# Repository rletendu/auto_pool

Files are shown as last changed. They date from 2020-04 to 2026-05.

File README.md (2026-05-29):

# AutoPool

ESP32 swimming-pool controller with pH / ORP / filter automation, Nextion touch UI, web dashboard, MQTT, and native Home Assistant autodiscovery.

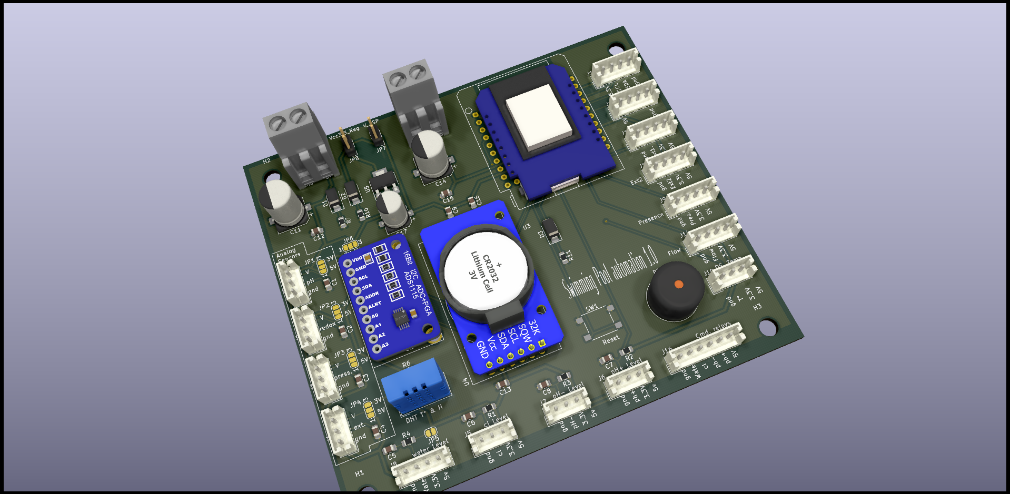
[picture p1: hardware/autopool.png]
AutoPool


AutoPool runs unattended on the side of the pool: it schedules the filter pump, doses chlorine on ORP, holds pH inside a target band by injecting acid (and optionally base) through peristaltic pumps, watches tank levels, and exposes everything over a 5″ touch panel, a web UI, and MQTT.

---

## Table of contents

- [Features](#features)
- [Hardware](#hardware)
- [Architecture](#architecture)
- [Build, flash and first boot](#build-flash-and-first-boot)
- [Configuration](#configuration)
- [MQTT](#mqtt)
- [Home Assistant integration](#home-assistant-integration)
- [Web UI and Nextion display](#web-ui-and-nextion-display)
- [OTA, CLI and Telnet](#ota-cli-and-telnet)
- [ESPHome alternative](#esphome-alternative)
- [Repository layout](#repository-layout)
- [Credits and license](#credits-and-license)

---

## Features

**Regulation**
- Filter pump scheduling — 24-hour fixed bitmap or per-temperature program (selected by `filter_auto_mode`)
- Filter speed control (FULL / REG) on a variable-speed pump
- Periodic short-cycle filter run for stagnation prevention
- pH minus (and optional pH plus) dosing on a fixed regulation cycle, proportional to deviation from target
- ORP / chlorine dosing on a fixed regulation cycle with daily mL caps
- Daily injection counters with automatic midnight reset (preserved across soft resets via RTC slow memory)

**Sensing**
- DS18B20 — water temperature (OneWire)
- DHT22 — air temperature and humidity inside the enclosure
- ADS1115 — pH probe, ORP probe, and pump-loop pressure transducer (3 channels)
- DS3231 — battery-backed RTC
- Four float switches — water level + Cl / pH- / pH+ tank levels

**Interfaces**
- Nextion 5″ resistive touch panel (`hmi/auto_pool_ui.HMI`)
- Responsive web dashboard served from SPIFFS (`http://<ip>/`)
- MQTT — measures, states, parameters, log, command, with **Home Assistant autodiscovery** (~40 entities) and LWT availability
- Serial CLI (`SimpleCLI`)
- OTA — firmware, SPIFFS filesystem, and Nextion display

---

## Hardware

The full schematic and PCB live in [`hardware/`](hardware/):

- [`hardware/autopool.pdf`](hardware/autopool.pdf) — schematic
- [`hardware/autopool.kicad_pcb`](hardware/autopool.kicad_pcb) — KiCad PCB
- [`hardware/autopool.png`](hardware/autopool.png), [`autopool_3.png`](hardware/autopool_3.png) — board renders
- [`3D/`](3D/) — printable enclosure parts (STL / STEP)

### Bill of materials (top level)

| Block | Part |
|---|---|
| MCU | ESP32 dev module |
| Display | Nextion 5″ (NX8048T050 or compatible) |
| Analog frontend | ADS1115 (I²C) for pH / ORP / pressure |
| RTC | DS3231 (I²C, battery-backed) |
| Air sensor | DHT22 |
| Water sensor | DS18B20 (OneWire) |
| Filter pump driver | Solid-state relay (active-high) |
| Dosing | 3× peristaltic pumps (Cl, pH-, pH+) on relays (active-low) |
| Levels | 4× float switches (water, Cl, pH-, pH+) |
| Misc | Piezo buzzer, two status LEDs |

### Pin map (excerpt, see [`src/board.h`](src/board.h) for the source of truth)

| Function | GPIO | Notes |
|---|---|---|
| Filter pump SSR | `PIN_EXT1` (14) | active **high** (`PUMP_FILTER_ACTIVE_VALUE = true`) |
| Filter speed (FULL/REG) | `PIN_EXT2` (15) | optional, gated by `HAS_FILTER_PWR_CTRL` |
| Cl pump relay | 25 | active **low** (`PUMP_ACTIVE_VALUE = false`) |
| pH- pump relay | 32 | active low |
| pH+ pump relay | 4 | active low, gated by `HAS_PH_PLUS_PUMP` |
| DS18B20 (water temp) | 13 | OneWire |
| DHT22 | 18 | |
| I²C (ADS1115, DS3231) | 21 / 22 | SDA / SCL |
| Nextion display | 16 / 17 | `Serial2` RX / TX, 115 200 baud |
| Float switches | 34, 35, 36, 39 | water / Cl / pH- / pH+ (input-only pins) |
| Buzzer | 5 | |

> **Polarity matters.** The filter pump SSR is wired through `PIN_EXT1` and is active-high; the dosing relays are active-low. Always go through the helpers in `board.h` (`pump_filtration_on/off`, `pump_ph_minus_on/off`, …) — never `digitalWrite` directly from feature code.

---

## Architecture

```
                    ┌────────────────────────┐
                    │       main.cpp         │
                    │  setup() / loop()      │
                    └──────────┬─────────────┘
                               │ SoftTimer ticks
        ┌──────────────┬───────┴───────┬──────────────┐
        ▼              ▼               ▼              ▼
  filter_control   ph_control     orp_control     measures
   (state machine) (state machine)(state machine) (sensor reads)
        │              │               │              │
        └────────┬─────┴────────┬──────┴──────┬───────┘
                 ▼              ▼             ▼
              board.h        state.h     parameters.h
            (HW helpers)   (live state)  (persisted setpoints)
                 │              │             │
                 ▼              ▼             ▼
        ┌────────────────────────────────────────────┐
        │   display  │  mqtt  │  server  │  cli  │ ota │
        └────────────────────────────────────────────┘
```

- **Cooperative scheduling** — every subsystem registers periodic work on a [`SoftTimer`](src/soft_timer.h) instance; no `delay()` in the main loop.
- **Three regulators** with explicit state machines defined in [`src/state.h`](src/state.h):
  - `filter_control_state_t` — IDLE → WARM_UP → ACTIVE → EXTENDED → PERIODIC
  - `ph_control_state_t` — IDLE / MINUS_INJECTION_{ON,OFF} / PLUS_INJECTION_{ON,OFF}
  - `orp_control_state_t` — IDLE / INJECTION_{ON,OFF}
- **Persistence** — two SPIFFS JSON files in [`data/`](data/):
  - `/config.json` ↔ `ParametersStruture` ([`src/parameters.h`](src/parameters.h))
  - `/state.json` ↔ last-known mode of each regulator (so a reboot does not reset operator intent)
- **Compile-time feature gates** in [`src/config.h`](src/config.h): `HAS_PH_CONTROL`, `HAS_ORP_CONTROL`, `HAS_FILTER_CONTROL`, `HAS_FILTER_PWR_CTRL`, `HAS_PH_PLUS_PUMP`, `HAS_MQTT`, `HAS_OTA`, `HAS_WEB_SERVER`, `HAS_CLI`, `HAS_TELNET_SERVER`, `HAS_QUIET_MEASURES`, `HAS_CUSTOM_MAC`.

---

## Build, flash and first boot

PlatformIO is the only toolchain. The single environment is `esp32dev`, defined in [`platformio.ini`](platformio.ini).

```bash
# Build
pio run

# Flash firmware over USB
pio run -t upload

# Flash firmware OTA
pio run -t upload --upload-port 192.168.x.x

# Flash the SPIFFS filesystem (web UI + config.json + state.json)
# Required after editing anything under data/
pio run -t uploadfs

# Serial monitor at 115 200 baud
pio device monitor

# Clean build
pio run -t clean
```

> **Firmware vs. filesystem are two independent flashes.** `pio run -t upload` writes the application binary (everything compiled from `src/`); `pio run -t uploadfs` writes the SPIFFS image built from `data/` (web UI, `config.json`, `state.json`). They're independent partitions on the ESP32 — flashing one never touches the other. Rules of thumb:
>
> - **Edited C/C++ in `src/` or `lib/`** → `pio run -t upload`. No `uploadfs` needed; settings and web assets are untouched.
> - **Edited anything under `data/`** (web UI, default `config.json`) → `pio run -t uploadfs`. No firmware reflash needed.
> - **Both** → run them in either order; e.g. `pio run -t upload && pio run -t uploadfs`.
> - **OTA**: both targets accept `--upload-port <ip>` to flash over Wi-Fi via `espota`, e.g. `pio run -t uploadfs --upload-port 192.168.x.x`.
> - **Heads up on `uploadfs`**: it overwrites `config.json` with the version in `data/`, wiping any settings the user changed via the web UI / portal / MQTT. Pull the live config back first (`curl http://<ip>/getparameters > data/config.json`) if you want to preserve it.

> **There are no unit tests** wired up. `test/autopool_tester.py` is a host-side helper, not a PlatformIO test runner.

### First boot

On first power-up the device opens a captive Wi-Fi portal named **`AUTOPOOL_CONFIG`**. Connect to it and configure:

- Wi-Fi SSID / password
- MQTT server / port / user / password
- MQTT base topic (default: `autopool`)

Settings persist to `/config.json` on SPIFFS. To re-trigger the portal later, send the `portal` CLI command on the serial console, or hit `/reboot` after wiping settings via `portal_reset`.

---

## Configuration

Three editing channels feed the same [`ParametersStruture`](src/parameters.h):

1. **Web UI** — `http://<ip>/settings.html` (form is bound by [`data/script_settings.js`](data/script_settings.js))
2. **MQTT** — publish a full JSON payload to `<base>/CMD/PARAMETERS`, or update one field at a time with `<base>/CMD/SET/<KEY>` *(see [MQTT](#mqtt))*
3. **WiFiManager portal** — for the network and broker fields only, on first boot or after `portal` / `portal_reset`

### Most-edited parameters

| Field | Meaning | Typical |
|---|---|---|
| `target_ph`, `delta_ph` | pH setpoint and dead-band | 7.4 ± 0.15 |
| `target_orp`, `delta_orp` | ORP setpoint (mV) and dead-band | 650 ± 70 |
| `flow_cl`, `flow_ph_minus`, `flow_ph_plus` | Peristaltic pump flow rate (mL/min) | 25 |
| `cl_max_day`, `phm_max_day` | Daily injection caps (mL) | 2000 |
| `pressure_warning` | Filter loop alarm threshold (bar) | 1.9 |
| `ph_offset`, `orp_offset` | Probe calibration offsets | 0 |
| `timer_prog` | 24-bit hourly bitmap for filter run | — |
| `filter_auto_mode` | `0` = bitmap, `1` = function of water temperature | 0 |
| `timer_prog_temperature[11]` | Per-temperature bitmaps (10 °C → 30 °C, step 2 °C) | — |
| `periodic_filter_time` | Seconds for short anti-stagnation cycle | 0 |
| `ha_discovery_enabled`, `ha_discovery_prefix` | HA autodiscovery toggle and topic prefix | `false`, `homeassistant` |

---

## MQTT

All topics are rooted at `<base>` (the value of `mqtt_base_topic`, default `autopool`).

### Published

| Topic | Retained | Payload |
|---|---|---|
| `<base>/AVAIL` | yes | `online` while the controller is up; `offline` published as LWT on disconnect |
| `<base>/MEAS` | no | JSON snapshot of [`MeasuresStructure`](src/measures.h) (temps, pH, ORP, pressure, levels, daily mL counters, boot count) |
| `<base>/STATE_FILTER` | no | JSON snapshot of the filter regulator state |
| `<base>/STATE_PH` | no | JSON snapshot of the pH± regulator state |
| `<base>/STATE_ORP` | no | JSON snapshot of the ORP regulator state |
| `<base>/PARAM` | no | Echo of the current `ParametersStruture` after any change |
| `<base>/LOG`, `<base>/DEBUG` | no | Free-form text |
| `<prefix>/+/autopool_<mac>/+/config` | yes | HA discovery configs (only when `ha_discovery_enabled` is set) |

### Subscribed (`<base>/CMD/<KEY>`)

**Mode commands** *(legacy string suffix, empty payload):*
`FILTER_MODE_AUTO` · `FILTER_MODE_ON` · `FILTER_MODE_OFF` · `FILTER_PWR_FULL` · `FILTER_PWR_REG` · `ORP_MODE_AUTO` · `ORP_MODE_ON` · `ORP_MODE_OFF`

**Per-field SET commands** *(payload = scalar value, suitable for HA selects/numbers):*

| Topic | Payload |
|---|---|
| `SET/FILTER_MODE` | `AUTO` \| `ON` \| `OFF` |
| `SET/FILTER_POWER` | `FULL` \| `REG` |
| `SET/ORP_MODE` | `AUTO` \| `ON` \| `OFF` |
| `SET/PH_MINUS_MODE` | `AUTO` \| `ON` \| `OFF` |
| `SET/PH_PLUS_MODE` | `AUTO` \| `ON` \| `OFF` |
| `SET/TARGET_PH`, `SET/DELTA_PH` | float |
| `SET/TARGET_ORP`, `SET/DELTA_ORP` | float (mV) |
| `SET/FLOW_CL`, `SET/FLOW_PH_MINUS`, `SET/FLOW_PH_PLUS` | float (mL/min) |
| `SET/CL_MAX_DAY`, `SET/PHM_MAX_DAY` | float (mL) |
| `SET/PRESSURE_WARNING` | float (bar) |
| `SET/PH_OFFSET`, `SET/ORP_OFFSET` | float (calibration) |
| `SET/PERIODIC_FILTER_TIME` | seconds |

Per-field SET commands persist to `/config.json` and echo on `<base>/PARAM`.

**JSON updates** *(payload = full JSON document):*
`PARAMETERS` · `MEASURES` · `FILTER_STATE` · `ORP_STATE` · `PH_STATE`

**Utility:** `RESET` · `RST_DAILY_ML_ORP` · `BEEP` · `GET_PARAMETERS` · `GET_STATES` · `LOG` · `FS`

---

## Home Assistant integration

Two paths, pick one.

### Autodiscovery (recommended)

1. Open the AutoPool web UI → **Settings** → tick **Enable autodiscovery**, leave the prefix as `homeassistant` unless your HA instance uses a custom one.
2. Click **Submit**. The controller publishes ~40 retained discovery configs under `<prefix>/+/autopool_<mac>/+/config`.
3. Home Assistant's MQTT integration picks them up automatically. AutoPool appears as a single device with:
   - Sensors — water / system temperature, humidity, pressure, pH, ORP, daily mL counters, boot count
   - Binary sensors — water level, three tank levels, four pump-running indicators
   - Selects — filter mode, filter power, ORP mode, pH± modes
   - Numbers — every setpoint listed in [Configuration](#configuration)
   - Buttons — controller reset, daily Cl counter reset
   - Diagnostic sensors — internal state of the three regulators
4. To remove the device: untick the checkbox; the controller publishes empty retained payloads to clear every discovery topic.

The companion dashboard at [`homeassistant/dashboards/autopool.yaml`](homeassistant/dashboards/autopool.yaml) is wired entirely to the autodiscovered entity_ids (`<domain>.autopool_<object>`, courtesy of the `obj_id` field in each discovery payload). It uses only stock Lovelace cards — no HACS install required. Drop it under `<HA_config>/dashboards/` and register it via the `lovelace.dashboards` block in [`homeassistant/configuration_snippet.yaml`](homeassistant/configuration_snippet.yaml).

### Multi-device deployment

Two AutoPool controllers can share a single MQTT broker and a single Home Assistant instance. Set `device_suffix` on each one — short, lowercase, `[a-z0-9_]`, max 12 chars (e.g. `north`, `south`, `pool1`). The suffix is spliced into:

| Identifier | Empty suffix | Suffix `north` |
|---|---|---|
| MQTT `client_id` | `AUTOPOOL` | `AUTOPOOL_north` |
| HA `obj_id` (entity_id slug) | `autopool_<object>` | `autopool_north_<object>` |
| HA device name | `AutoPool` | `AutoPool north` |
| WiFiManager portal SSID | `AUTOPOOL_CONFIG` | `AUTOPOOL_CONFIG_north` |
| OTA mDNS hostname | `autopool.local` | `autopool-north.local` |

`mqtt_base_topic` is also auto-rewritten when you set the suffix via `<base>/CMD/SET/DEVICE_SUFFIX` (and only if the topic still has the legacy default `autopool` / empty). Set it manually otherwise via the WiFi portal or web UI to keep the two devices on disjoint topic trees.

Caveats:
- The very first portal setup of a fresh unit always uses the legacy SSID `AUTOPOOL_CONFIG` (suffix is set inside the portal itself). Configure both units sequentially the first time, not simultaneously.
- After changing a non-empty suffix, HA's old entities go to *unavailable* until the next HA restart — the controller publishes empty retained payloads to the old discovery topics so they age out cleanly.
- The supplied dashboard at [`homeassistant/dashboards/autopool.yaml`](homeassistant/dashboards/autopool.yaml) targets a single device with empty suffix. For multi-device dashboards, copy the file and `sed 's/autopool_/autopool_<suffix>_/g'` to retarget.

### Manual packages (legacy)

If you'd rather not run discovery, the older path still works: copy [`homeassistant/packages/autopool.yaml`](homeassistant/packages/autopool.yaml) and [`homeassistant/custom_templates/autopool.jinja`](homeassistant/custom_templates/autopool.jinja) into your HA config, enable `packages: !include_dir_named packages` in `configuration.yaml`, and **disable** the autodiscovery toggle on the controller — running both at once creates duplicate entities. The header of `packages/autopool.yaml` documents the migration trade-offs.

---

## Web UI and Nextion display

### Web UI

Served by [`src/server.cpp`](src/server.cpp) from SPIFFS:

- `/` — live dashboard (measures, daily counters)
- `/settings.html` — full configuration form
- `/getmeasures`, `/getparameters`, `/getfilterstate`, `/getorpstate`, `/getphstate` — JSON endpoints used by the dashboard
- `/setparameters` — POST endpoint backing the settings form
- `/filter_auto`, `/filter_on`, `/filter_off`, `/filter_pwr_full`, `/filter_pwr_reg`, `/orp_*`, `/ph_*` — quick-action buttons
- `/reboot`, `/rst_daily_ml_orp` — maintenance
- `/edit`, `/list`, `/fs` — SPIFFS file browser

### Nextion display

- HMI source: [`hmi/auto_pool_ui.HMI`](hmi/auto_pool_ui.HMI) (open in Nextion Editor)
- Pre-built TFT firmware lives under [`hmi/tft/`](hmi/tft/) — flash directly from an SD card, or push over the air via [`src/ota_tft.cpp`](src/ota_tft.cpp) (uses [`lib/ESPNexUpload`](lib/ESPNexUpload))
- Display drives `Serial2` (`PIN_RX2 = 16`, `PIN_TX2 = 17`) at 115 200 baud
- Firmware references widgets by name in [`src/display_components.cpp`](src/display_components.cpp); add new touch callbacks in [`src/display.cpp`](src/display.cpp)

---

## OTA, CLI and Telnet

- **Firmware OTA** — ArduinoOTA, invoked via `pio run -t upload --upload-port <ip>`
- **Filesystem OTA** — same syntax with `-t uploadfs`
- **Display OTA** — streamed by `ESPNexUpload`, triggered from the web UI / MQTT
- **Serial CLI** — three commands today (parsed by `SimpleCLI` in [`src/cli.cpp`](src/cli.cpp)):
  - `portal` — open the Wi-Fi captive portal and reboot
  - `portal_reset` — wipe Wi-Fi credentials and reboot
  - `format` — format SPIFFS (destructive)
- **Telnet** — off by default (`HAS_TELNET_SERVER 0` in [`src/config.h`](src/config.h)); flips on a `RemoteDebug` server when enabled

---

## ESPHome alternative

[`autopool_esphome.yaml`](autopool_esphome.yaml) is a parallel, in-progress port of the same hardware to ESPHome. The PlatformIO firmware in [`src/`](src/) remains the authoritative implementation. Migration notes / design log: [`2026-04-24-migration_esphome.txt`](2026-04-24-migration_esphome.txt). Secrets for the ESPHome flavour go in `secrets.yaml` (gitignored).

---

## Repository layout

```
src/                   Firmware (Arduino / PlatformIO) — main.cpp + per-subsystem modules
data/                  SPIFFS payload (web UI, config.json, state.json)
lib/                   Vendored libraries: Nextion, WiFiManager, RemoteDebug, SerialDebug, ESPNexUpload
hardware/              KiCad schematic, PCB, renders, gerbers
3D/                    Enclosure parts (STL / STEP)
hmi/                   Nextion HMI source + compiled .tft + assets
homeassistant/         Drop-in HA packages, dashboard, Jinja templates, integration snippet
autopool_esphome.yaml  Experimental ESPHome rewrite
platformio.ini         Build config (single env: esp32dev)
CLAUDE.md              Architecture / contributor guide (also used by AI assistants)
```

---

## Credits and license

Author: **Raphaël Letendu** — [github.com/rletendu/auto_pool](https://github.com/rletendu/auto_pool).

Vendored library licenses live alongside each library under [`lib/*/LICENSE*`](lib/). The repository does not currently carry a top-level `LICENSE` file; if you intend to publish the firmware, add one (MIT or GPL-2.0+ are common picks for ESP32 hobby projects).

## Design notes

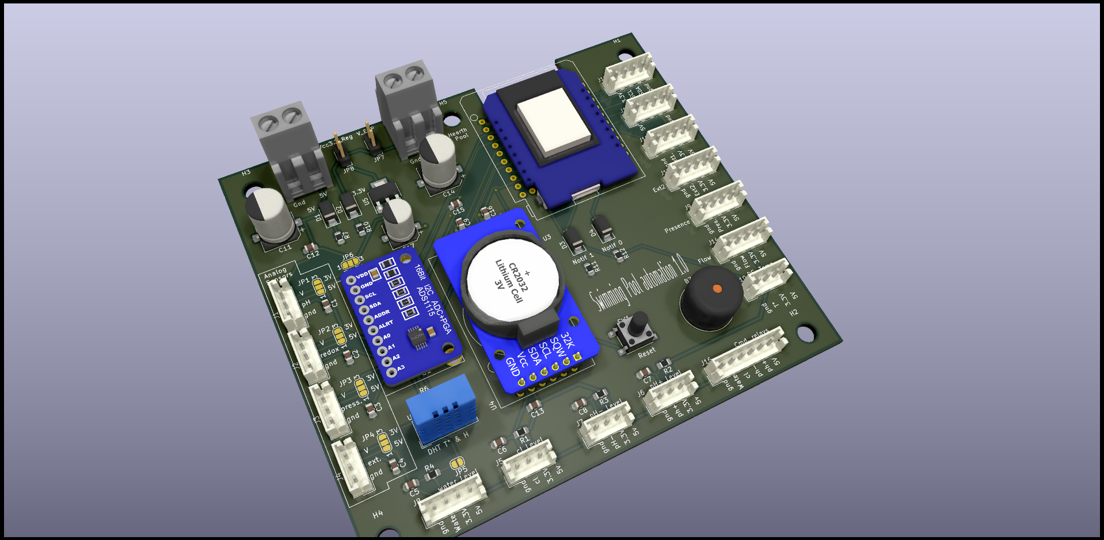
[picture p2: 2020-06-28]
hardware/autopool_4.png

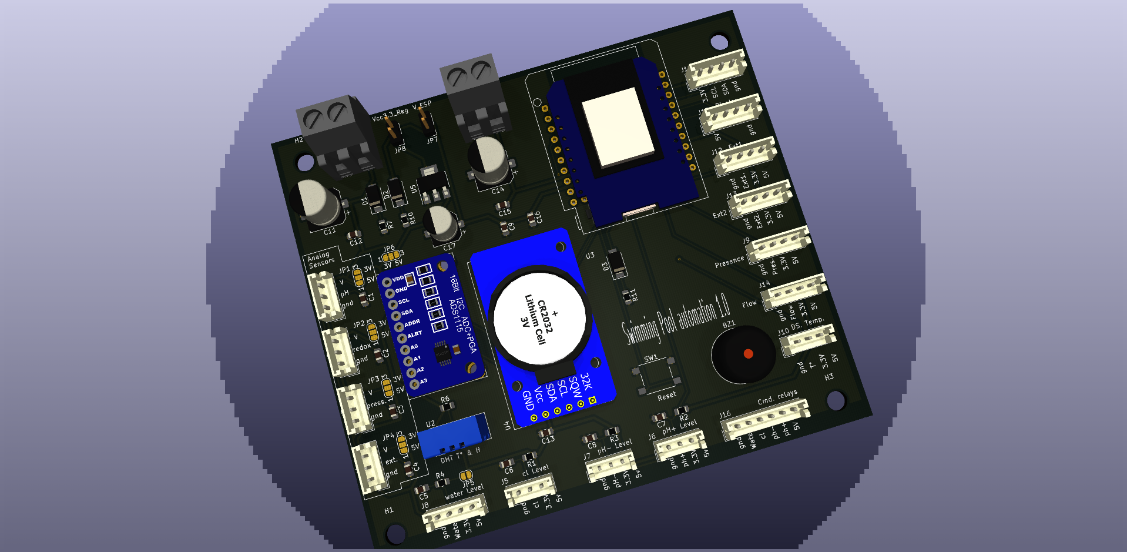
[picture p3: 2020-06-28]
hardware/autopool_2.png

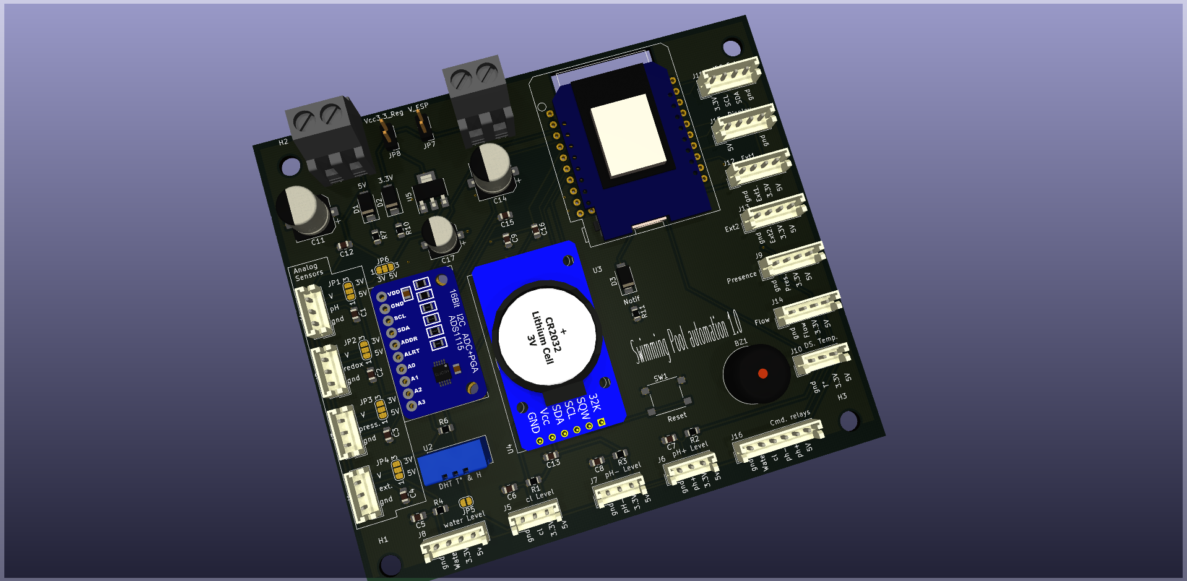
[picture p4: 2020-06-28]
hardware/autopool_3.png

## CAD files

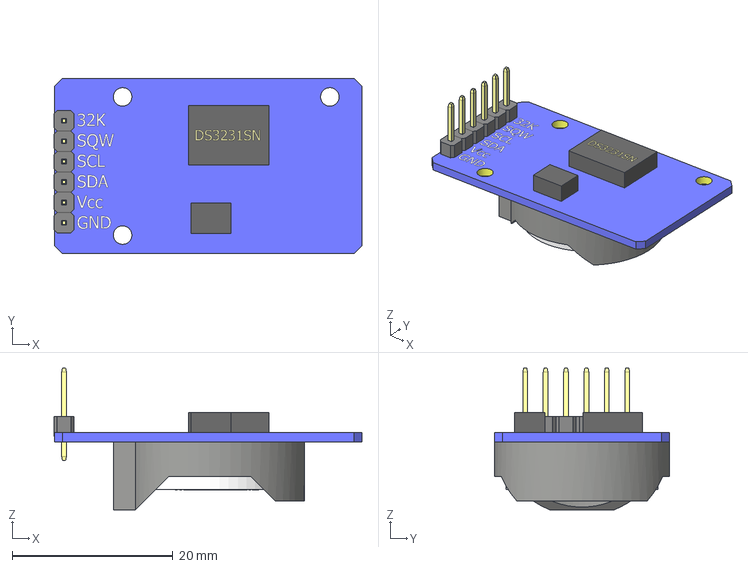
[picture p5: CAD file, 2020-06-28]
hardware/3D/DS3231 Timer Assembly.stp
38.3 x 21.8 x 17.6 mm

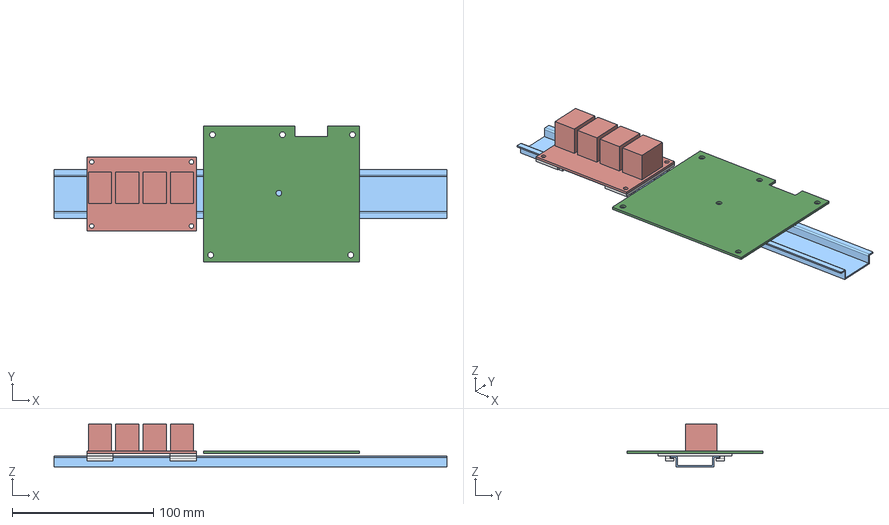
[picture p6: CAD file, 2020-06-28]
3D/autopool_box_vertical19.FCStd
278.0 x 96.5 x 30.1 mm
base x 2
griffes x 2

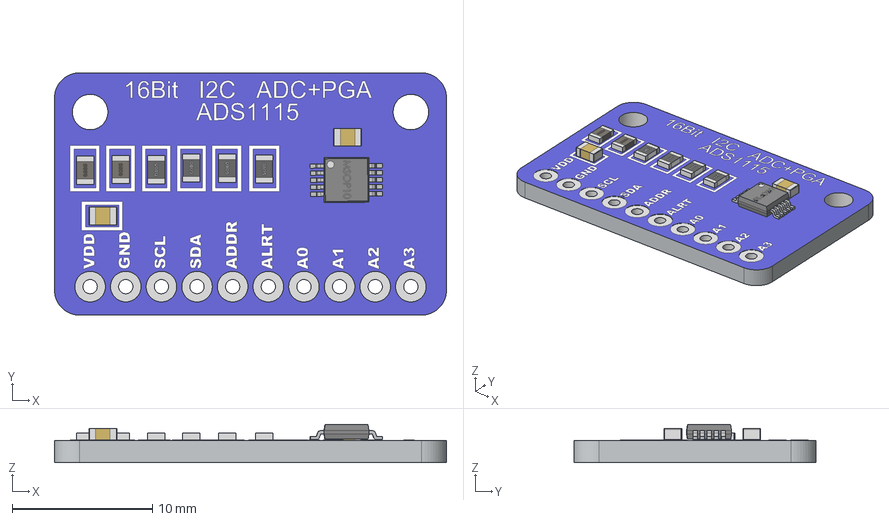
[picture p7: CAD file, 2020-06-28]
hardware/3D/16Bit I2C ADC+PGA - ADS1115.stp
27.9 x 17.3 x 2.74 mm
ADS1115
0805 Capacitor x 2
0805 Inductor x 2
0805 Resistor x 4
MSOP10

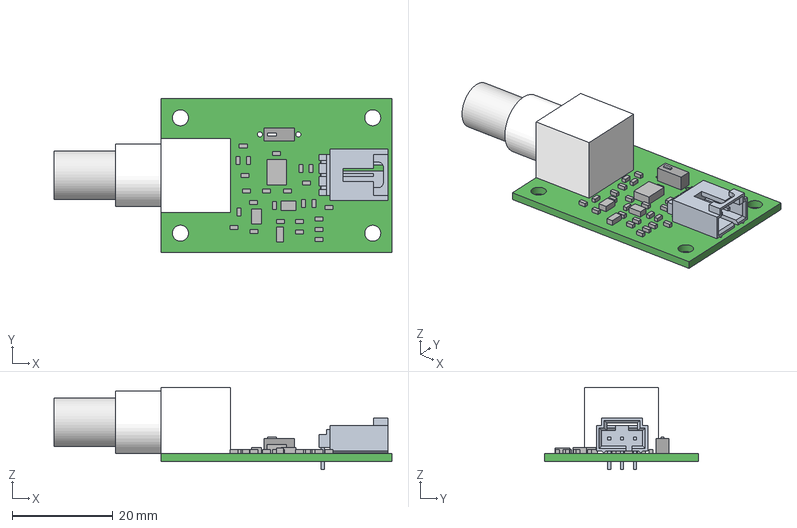
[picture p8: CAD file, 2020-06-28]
hardware/Assembly/1130_0.step
67.0 x 30.5 x 16.3 mm
Board
Extruded x 32

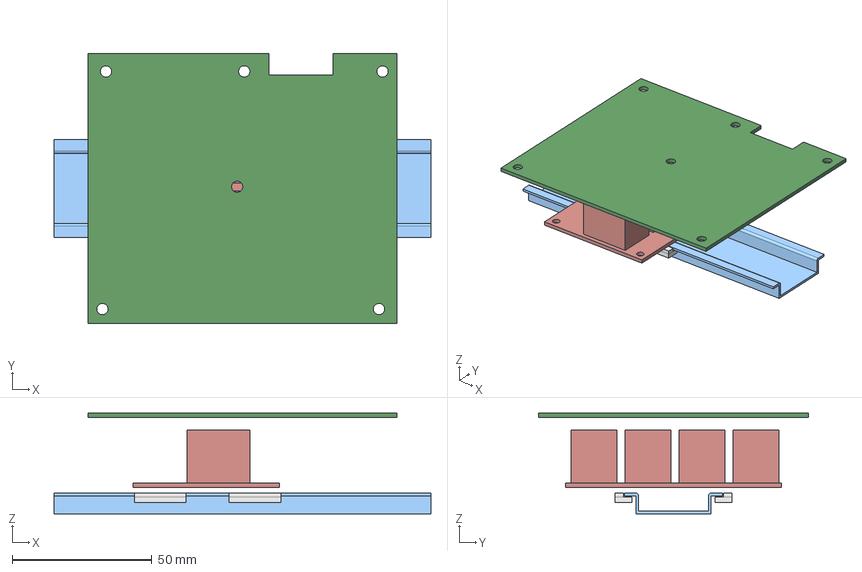
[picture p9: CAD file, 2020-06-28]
3D/autopool_box19b.FCStd
135.0 x 96.5 x 36.1 mm
griffes x 2

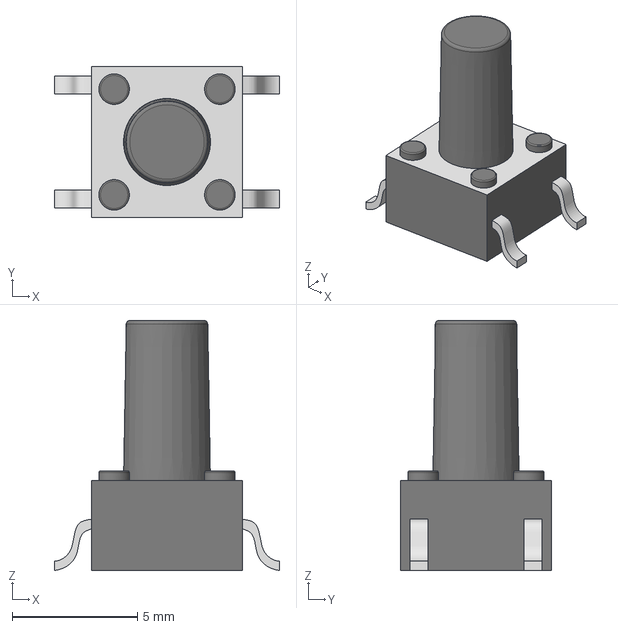
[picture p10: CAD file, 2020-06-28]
hardware/3D/Tactal Switch - SMD (6mmx 6mmx 10mm) - Marked.stp
9.02 x 6.03 x 10.0 mm

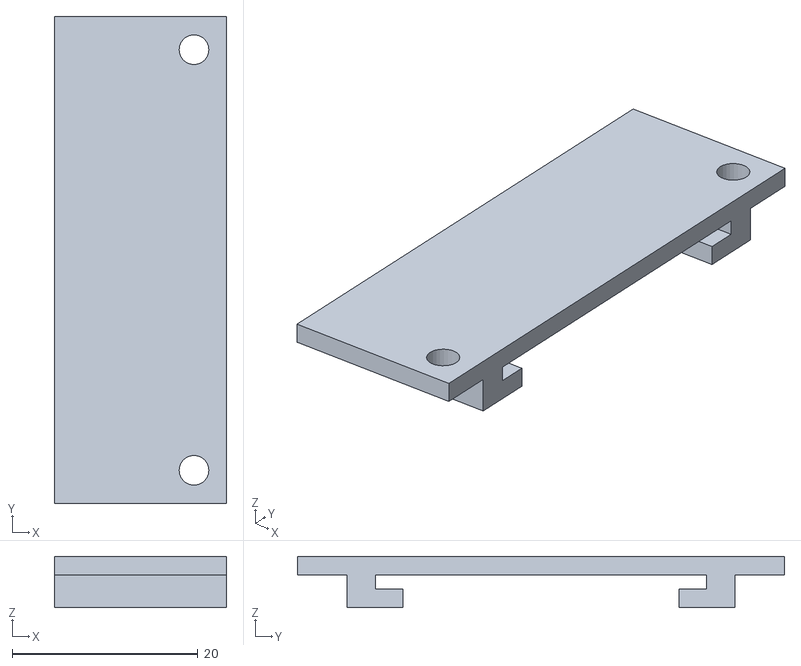
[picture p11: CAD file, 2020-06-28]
3D/sup.stl
18.5 x 52.5 x 5.50

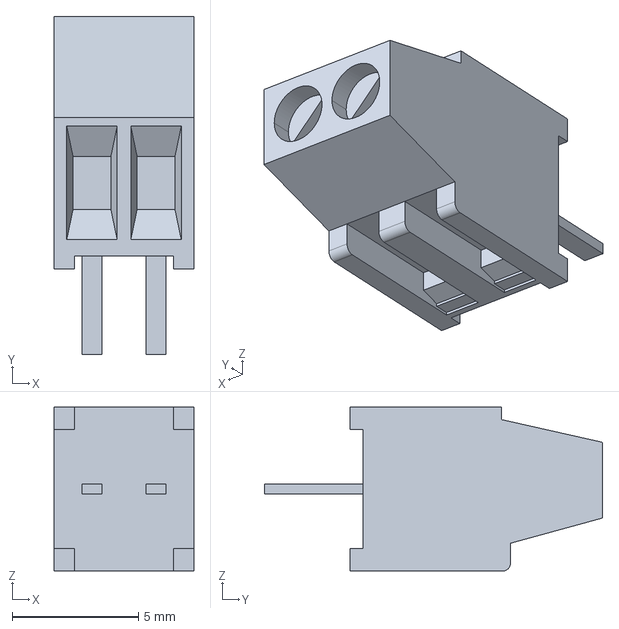
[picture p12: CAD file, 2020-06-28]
hardware/3D/bornier.stp
5.54 x 13.4 x 6.50 mm

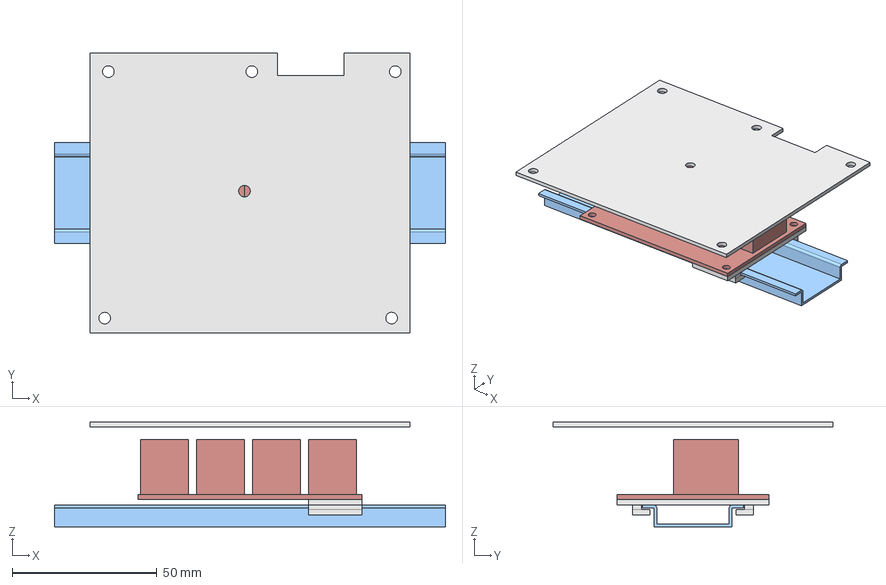
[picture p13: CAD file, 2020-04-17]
3D/autopool_box.FCStd
135.0 x 96.5 x 36.1 mm
base
griffes

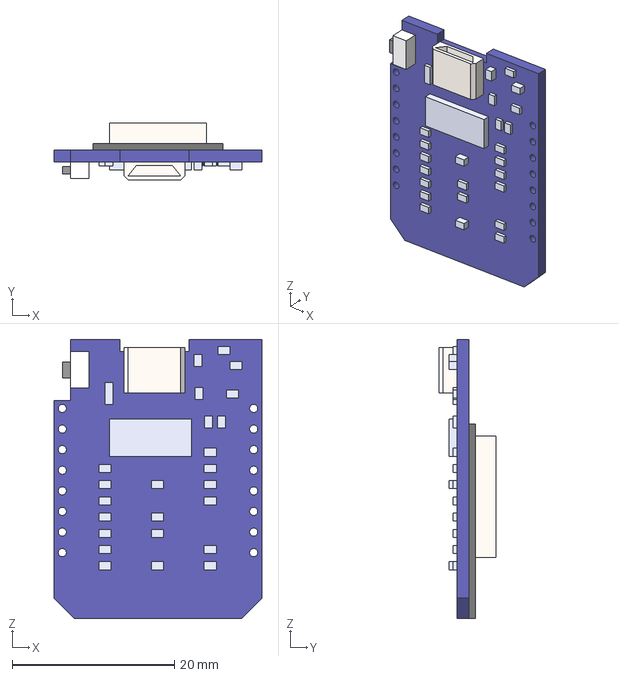
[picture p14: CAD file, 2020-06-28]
hardware/3D/WEMOS D1 mini.step
25.6 x 7.00 x 34.4 mm

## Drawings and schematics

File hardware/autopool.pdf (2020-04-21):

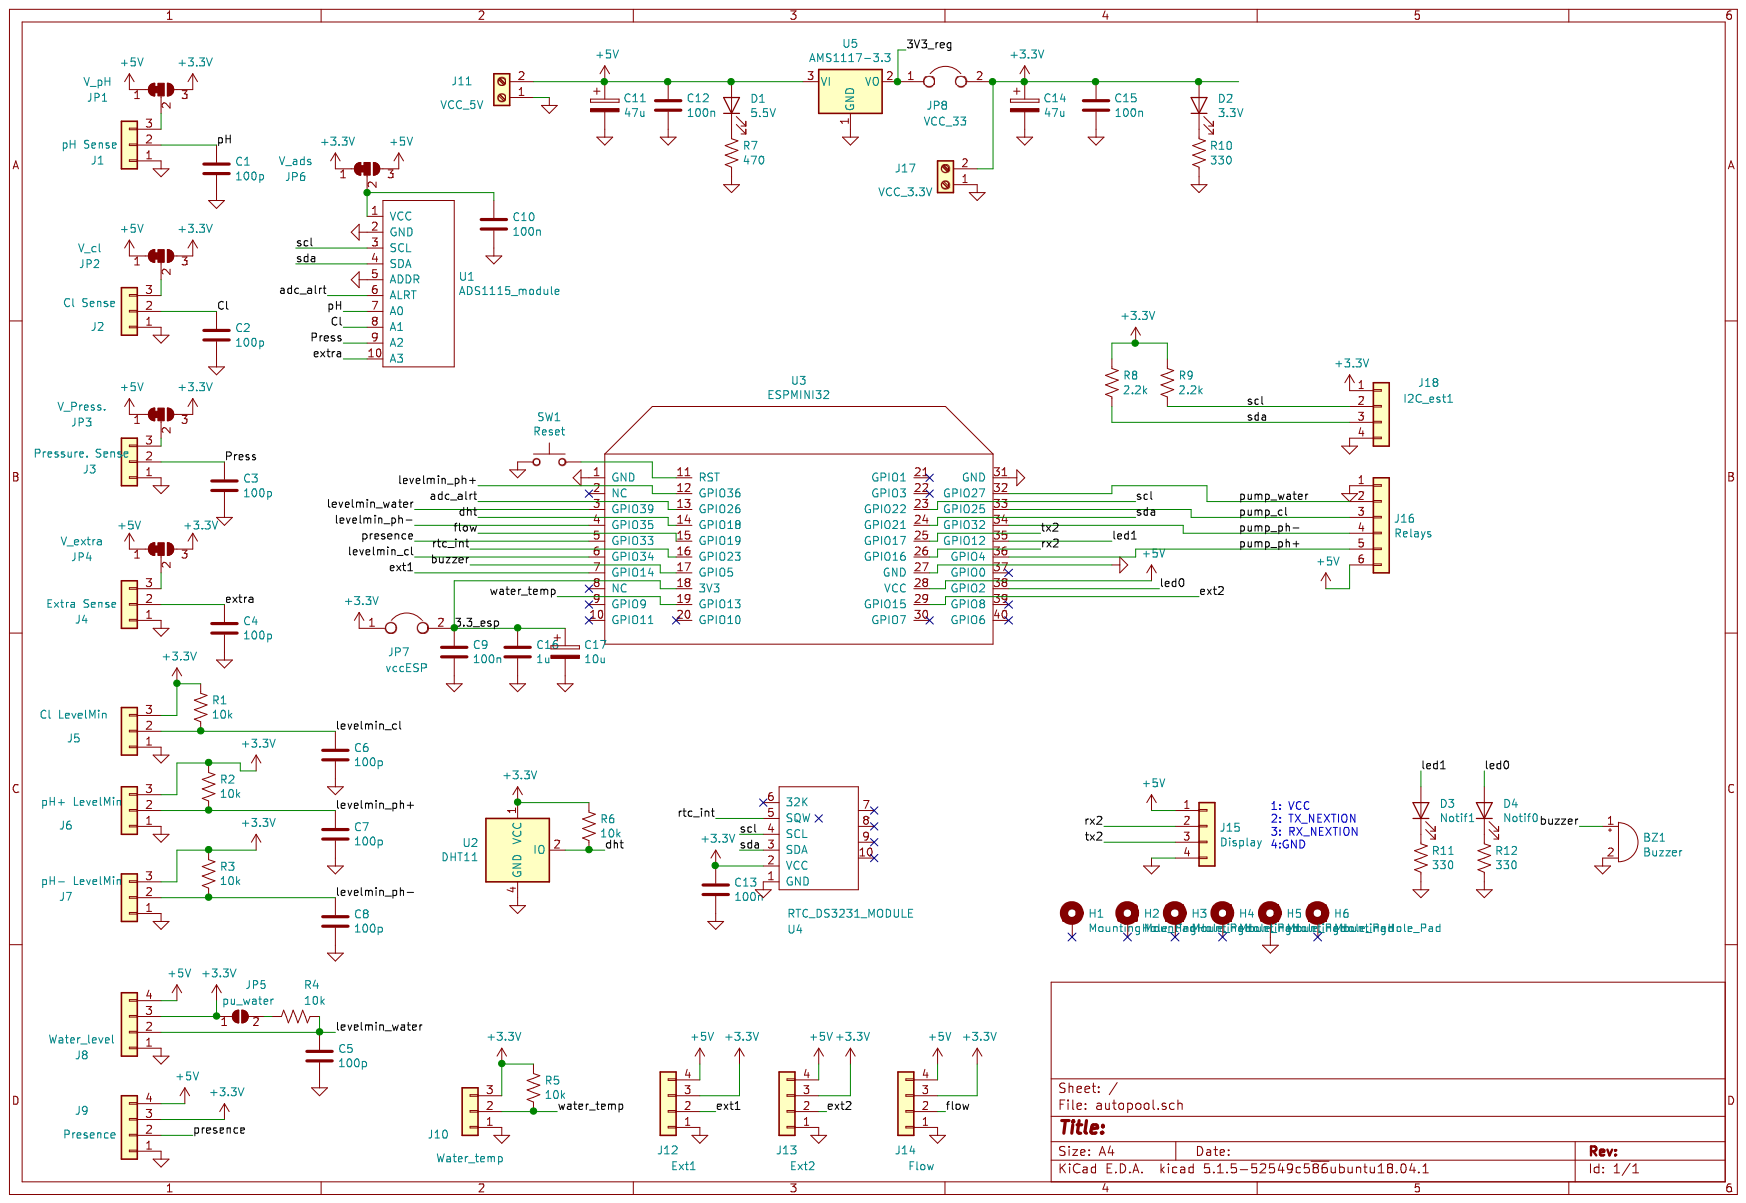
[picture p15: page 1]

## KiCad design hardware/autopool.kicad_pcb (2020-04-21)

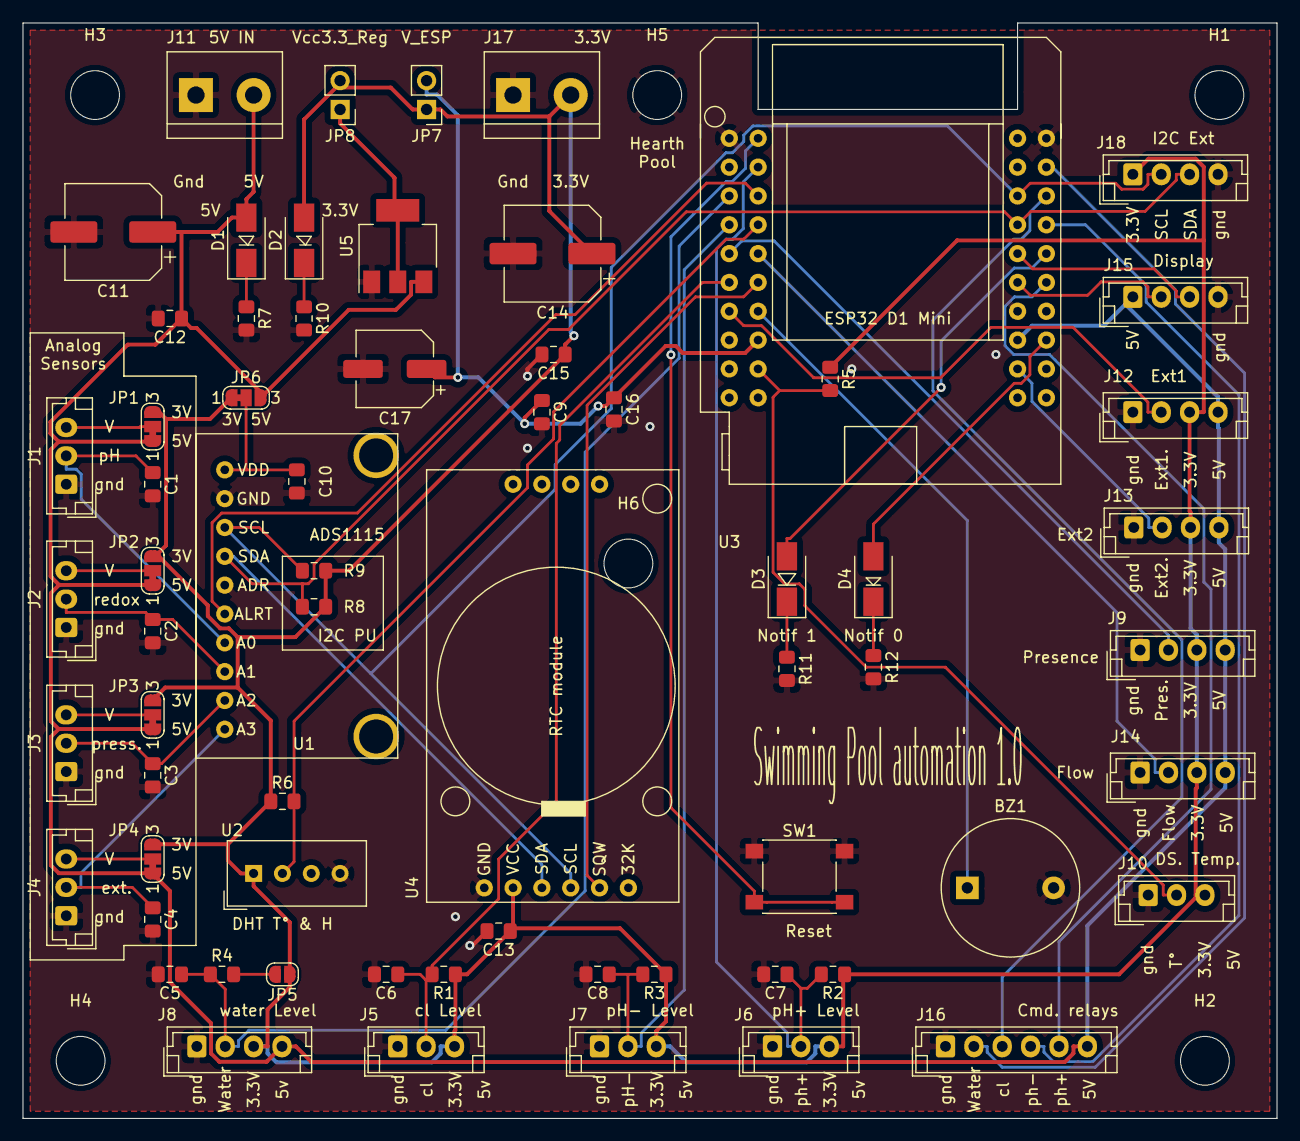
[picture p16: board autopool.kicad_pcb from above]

Board: 2 copper layers, 110.5 x 96.5 mm, 72 parts (0 on the bottom side), 43 nets.

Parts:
BZ1: Buzzer; Buzzer_12x9.5RM7.6
C1, C2, C3, C4, C5, C6, C7, C8: 100p; C_0805_2012Metric_Pad1.15x1.40mm_HandSolder
C9, C10, C12, C13, C15: 100n; C_0805_2012Metric_Pad1.15x1.40mm_HandSolder
C11, C14: 47u; CP_Elec_8x11.9
C16: 1u; C_0805_2012Metric_Pad1.15x1.40mm_HandSolder
C17: 10u; CP_Elec_6.3x9.9
D1: 5.5V; D_SMA
D2: 3.3V; D_SMA
D3: Notif1; D_SMA
D4: Notif0; D_SMA
H1, H2, H3, H4, H5, H6: MountingHole_Pad; MountingHole_4.3mm_M4
J1: pH Sense; JST_EH_B3B-EH-A_1x03_P2.50mm_Vertical
J2: Cl Sense; JST_EH_B3B-EH-A_1x03_P2.50mm_Vertical
J3: Pressure. Sense; JST_EH_B3B-EH-A_1x03_P2.50mm_Vertical
J4: Extra Sense; JST_EH_B3B-EH-A_1x03_P2.50mm_Vertical
J5: Cl LevelMin; JST_EH_B3B-EH-A_1x03_P2.50mm_Vertical
J6: pH+ LevelMin; JST_EH_B3B-EH-A_1x03_P2.50mm_Vertical
J7: pH- LevelMin; JST_EH_B3B-EH-A_1x03_P2.50mm_Vertical
J8: Water_level; JST_EH_B4B-EH-A_1x04_P2.50mm_Vertical
J9: Presence; JST_EH_B4B-EH-A_1x04_P2.50mm_Vertical
J10: Water_temp; JST_EH_B3B-EH-A_1x03_P2.50mm_Vertical
J11: VCC_5V; TerminalBlock_bornier-2_P5.08mm
J12: Ext1; JST_EH_B4B-EH-A_1x04_P2.50mm_Vertical
J13: Ext2; JST_EH_B4B-EH-A_1x04_P2.50mm_Vertical
J14: Flow; JST_EH_B4B-EH-A_1x04_P2.50mm_Vertical
J15: Display; JST_EH_B4B-EH-A_1x04_P2.50mm_Vertical
J16: Relays; JST_EH_B6B-EH-A_1x06_P2.50mm_Vertical
J17: VCC_3.3V; TerminalBlock_bornier-2_P5.08mm
J18: I2C_est1; JST_EH_B4B-EH-A_1x04_P2.50mm_Vertical
JP1: V_pH; SolderJumper-3_P1.3mm_Bridged12_RoundedPad1.0x1.5mm_NumberL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
JP2: V_cl; SolderJumper-3_P1.3mm_Bridged12_RoundedPad1.0x1.5mm_NumberL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
JP3: V_Press.; SolderJumper-3_P1.3mm_Bridged12_RoundedPad1.0x1.5mm_NumberL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
JP4: V_extra; SolderJumper-3_P1.3mm_Bridged12_RoundedPad1.0x1.5mm_NumberL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
JP5: pu_water; SolderJumper-2_P1.3mm_Open_RoundedPad1.0x1.5mm
JP6: V_ads; SolderJumper-3_P1.3mm_Bridged12_RoundedPad1.0x1.5mm_NumberL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
JP7: vccESP; PinHeader_1x02_P2.54mm_Vertical
JP8: VCC_33; PinHeader_1x02_P2.54mm_Vertical
R1, R2, R3, R4, R5, R6: 10k; R_0805_2012Metric_Pad1.15x1.40mm_HandSolder
R7: 470; R_0805_2012Metric_Pad1.15x1.40mm_HandSolder
R8, R9: 2.2k; R_0805_2012Metric_Pad1.15x1.40mm_HandSolder
R10, R11, R12: 330; R_0805_2012Metric_Pad1.15x1.40mm_HandSolder
SW1: Reset; SW_Push_1P1T_NO_6x6mm_H9.5mm
U1: ADS1115_module
U2: DHT11; Aosong_DHT11_5.5x12.0_P2.54mm
U3: ESPMINI32; esp32_mini
U4: RTC_DS3231_MODULE; RTC_DS3231_MODULE_H
U5: AMS1117-3.3; SOT-223-3_TabPin2

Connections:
+3V3: C13.1, C14.1, C15.1, D2.2, J5.3, J6.3, J7.3, J8.3, J9.3, J10.3, J12.3, J13.3, J14.3, J17.2, J18.1, JP1.3, JP2.3, JP3.3, JP4.3, JP5.1, JP6.1, JP7.1, JP8.2, R1.1, R2.1, R3.1, R5.1, R6.1, R8.1, R9.1, U2.1, U4.2
+5V: C11.1, C12.1, D1.2, J8.4, J9.4, J11.2, J12.4, J13.4, J14.4, J15.1, J16.6, JP1.1, JP2.1, JP3.1, JP4.1, JP6.3, U3.28, U5.3
/3.3_esp: C9.1, C16.1, C17.1, JP7.2, U3.18
/3V3_reg: JP8.1, U5.2
/Cl: C2.1, J2.2, U1.8
/Press: C3.1, J3.2, U1.9
/adc_alrt: U1.6, U3.13
/buzzer: BZ1.1, U3.17
/dht: R6.2, U2.2, U3.14
/ext1: J12.2, U3.7
/ext2: J13.2, U3.29
/extra: C4.1, J4.2, U1.10
/flow: J14.2, U3.15
/led0: D4.2, U3.38
/led1: D3.2, U3.35
/levelmin_cl: C6.1, J5.2, R1.2, U3.6
/levelmin_ph+: C7.1, J6.2, R2.2, U3.12
/levelmin_ph-: C8.1, J7.2, R3.2, U3.4
/levelmin_water: C5.1, J8.2, R4.1, U3.3
/pH: C1.1, J1.2, U1.7
/presence: J9.2, U3.5
/pump_cl: J16.3, U3.33
/pump_ph+: J16.5, U3.36
/pump_ph-: J16.4, U3.34
/pump_water: J16.2, U3.32
/rtc_int: U3.16, U4.5
/rx2: J15.2, U3.26
/scl: J18.2, R9.2, U1.3, U3.23, U4.4
/sda: J18.3, R8.2, U1.4, U3.24, U4.3
/tx2: J15.3, U3.25
/water_temp: J10.2, R5.2, U3.19
GND: BZ1.2, C1.2, C2.2, C3.2, C4.2, C5.2, C6.2, C7.2, C8.2, C9.2, C10.2, C11.2, C12.2, C13.2, C14.2, C15.2, C16.2, C17.2, H5.1, J1.1, J2.1, J3.1, J4.1, J5.1, J6.1, J7.1, J8.1, J9.1, J10.1, J11.1, J12.1, J13.1, J14.1, J15.4, J16.1, J17.1, J18.4, R7.2, R10.2, R11.2, R12.2, SW1.1, U1.2, U1.5, U2.4, U3.1, U3.27, U3.31, U4.1, U5.1
unnamed: C10.1, JP6.2, U1.1
unnamed: D1.1, R7.1
unnamed: D2.1, R10.1
unnamed: D3.1, R11.1
unnamed: D4.1, R12.1
unnamed: J1.3, JP1.2
unnamed: J2.3, JP2.2
unnamed: J3.3, JP3.2
unnamed: J4.3, JP4.2
unnamed: JP5.2, R4.2
unnamed: SW1.2, U3.11

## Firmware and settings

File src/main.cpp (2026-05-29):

#include "autopool.h"

SoftTimer timer_pool = SoftTimer();
uintptr_t time_update_task;

int bootCount RTC_NOINIT_ATTR;
RTC_NOINIT_ATTR float daily_ml_ph_minus_backup;
RTC_NOINIT_ATTR float daily_ml_ph_plus_backup;
RTC_NOINIT_ATTR float daily_ml_orp_backup;
RTC_NOINIT_ATTR uint32_t daily_filter_min_backup;
RTC_NOINIT_ATTR uint32_t total_filter_min_backup;
uint32_t boot_key RTC_NOINIT_ATTR;

void time_update_stop(void)
{
	timer_pool.cancel(time_update_task);
}

bool time_update(void *)
{
	char msg[20];
	printlnA(F("Time Update..."));
	sprintf(msg, "%02u/%02u/%02u %02u:%02u", rtc_get_day(), rtc_get_month(), rtc_get_year(), rtc_get_hour(), rtc_get_minute());
	dis_sys_hour.setText(msg);

	// Per-minute filter runtime accumulation
	if (pump_filtration_is_on())
	{
		measures.daily_filter_min++;
		measures.total_filter_min++;
	}

	if (rtc_get_hour() == 0 && rtc_get_minute() == 0)
	{
		measures.daily_ml_ph_minus = 0;
		measures.daily_ml_ph_plus = 0;
		measures.daily_ml_orp = 0;
		measures.daily_filter_min = 0;
		mqtt_publish_log("Reset injecion counters and max water temperature");
		measures.day_max_water_temperature = measures.water_temperature_raw;
		// Persist total_filter_min so it survives full power loss
		state.total_filter_min = measures.total_filter_min;
		state_default_write_file();
	}
	// Backup injection counters in RTC memory
	daily_ml_ph_minus_backup = measures.daily_ml_ph_minus;
	daily_ml_ph_plus_backup = measures.daily_ml_ph_plus;
	daily_ml_orp_backup = measures.daily_ml_orp;
	daily_filter_min_backup = measures.daily_filter_min;
	total_filter_min_backup = measures.total_filter_min;

	disp_progress_hour.setValue((uint8_t)map(rtc_get_hour()*60+rtc_get_minute(), 0, 24*60, 0, 100));
	printlnA(F("Time Update Done"));
	return true; // repeat? true
}

void rtc_init()
{
	struct tm timeinfo;
	if (!getLocalTime(&timeinfo))
	{
		printlnA(F("Failed to sync internet time"));
		return;
	}
	timeinfo.tm_year -= 100;
	timeinfo.tm_mon += 1;
	rtc_set_time(timeinfo);
	Serial.println(&timeinfo, "%A, %B %d %Y %H:%M:%S");
}

void setup()
{
	char msg[80];
	if (boot_key == BOOT_KEY_MAGIC)
	{
		bootCount++;
	}
	else
	{
		bootCount = 0;
	}

	Serial.begin(115200);
	//parameters_format();

	board_init();
	display_log_clear();

	printlnA(F("AutoPool Starting..."));
	sprintf(msg, "AutoPool %.2f %s %s starting", AUTOPOOL_VER, __DATE__, __TIME__);
	disp_boot_progress_message(msg);
	sprintf(msg, "Rev: %.2f : %s %s", AUTOPOOL_VER, __DATE__, __TIME__);
	boot_version.setText(msg);
	disp_options_version.setText(msg);
	delay(500);

	#if HAS_CUSTOM_MAC
	#error CUSTUM MAC not working yet !
	uint8_t newMACAddress[] = CUSTOM_MAC;
	esp_wifi_set_mac(ESP_IF_WIFI_STA, &newMACAddress[0]);
	#endif

	disp_options_mac.setText(WiFi.macAddress().c_str());
	wifimanager_init();
	if (wifimanager_autoconnect())
	{
		IPAddress ip = WiFi.localIP();
		printA(F("Ip Address : "));
		printlnA(ip);
		sprintf(msg, "Wifi Connected : %d.%d.%d.%d", ip[0], ip[1], ip[2], ip[3]);
		disp_boot_progress_message(msg);
		sprintf(msg, "Wifi IP : %d.%d.%d.%d", ip[0], ip[1], ip[2], ip[3]);
		boot_ip.setText(msg);
		sprintf(msg, "%d.%d.%d.%d", ip[0], ip[1], ip[2], ip[3]);
		disp_options_ip.setText(msg);
	}
	else
	{
		page_boot.show();
		printlnA("Wifi Not Connected!:");
		disp_boot_progress_message("Wifi Not Connected !");
		boot_ip.setText("Wifi IP : ---:---:---:---");
	}
	wifi_monitor();

	if (parameters_read_file())
	{
		disp_boot_progress_message("Loading config file : Ok");
		printlnA("Reading config file OK");
	}
	else
	{
		disp_boot_progress_message("Loading config File Fail");
		printlnA("Reading config file failed");
	}

#if HAS_OTA
	disp_boot_progress_message("OTA Init");
	ota_init();
#endif

#if HAS_MQTT
	disp_boot_progress_message("MQTT Init");
	mqtt_init();
#endif


#if HAS_CLI
	disp_boot_progress_message("CLI Init");
	cli_init();
#endif

	disp_boot_progress_message("RTC Init");
	configTime(GMTOFFSET, DAYLIGHTOFFSET, NTPSERVER);
	rtc_init();

	if (state_default_read_file())
	{
		printlnA(F("State.json file read sucessfully"));
		printA("Read filter mode : ");
		printlnA(state_default.filter_mode);
	}
	else
	{
		printlnA(F("Could not read State.json file, applying default"));
		state_default.filter_mode = FILTER_AUTO;
		state_default.ph_minus_mode = PH_MINUS_AUTO;
		state_default.ph_plus_mode = PH_PLUS_OFF;
		state_default.orp_mode = ORP_AUTO;
		state_default.filter_power = FILTER_POWER_FULL;
	}

	disp_boot_progress_message("Filter Control Init");
	filter_control_init();

	disp_boot_progress_message("ORP Control Init");
	orp_control_init();

	disp_boot_progress_message("pH Control Init");
	ph_control_init();

	disp_boot_progress_message("Measure Init");
	measures_init();

#if HAS_WEB_SERVER
	disp_boot_progress_message("Web Server Init");
	webserver_init();
#endif

#if HAS_TELNET_SERVER
	disp_boot_progress_message("Telnet Server Init");
	telnet_init();
#endif

	//save the custom parameters to FS
	if (is_should_save_config())
	{
		printlnA(F("Need to write Json config file..."));
		parameters_write_file();
	}

	time_update_task = timer_pool.every(60 * 1000, time_update);
	printlnA(F("Init Done..."));

	boot_key = BOOT_KEY_MAGIC;
	char boot_msg[25];
	sprintf(boot_msg, "Autopool rebooted (%u)", measures.boot_count);
	log_append(boot_msg);
	time_update(NULL);
	page_status.show();
//	disp_progress_hour.setValue((uint8_t)map(rtc_get_hour()*60+rtc_get_minute(), 0, 24*60, 0, 100));
//	disp_progress_filter.setValue(85);
}

volatile unsigned long tmp = 0;
volatile unsigned long target = 0x5000;
unsigned long duration;

void loop()
{
	timer_pool.tick(); // tick the timer
#if HAS_OTA
	ota_loop();
#endif
	display_loop(); // Proceed display touch events
#if HAS_MQTT
	mqtt_loop();
#endif

#if HAS_CLI
	cli_loop(); // Serial command line input
#endif
#if HAS_WEB_SERVER
	webserver_loop();
#endif
#if HAS_TELNET_SERVER
	telnet_loop();
#endif
}

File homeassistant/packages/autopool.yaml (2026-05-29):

# =============================================================================
# AutoPool — Home Assistant entities for the MQTT firmware (no HA discovery)
# -----------------------------------------------------------------------------
# LEGACY — superseded by autodiscovery.
#
# As of the autodiscovery branch, the controller publishes every entity HA
# needs via the `homeassistant/...` discovery topics; the dashboard at
# `dashboards/autopool.yaml` is wired to those autodiscovered entity_ids and
# does NOT reference this package. Loading both at once produces duplicate
# entities and broken templates.
#
# Use this file ONLY if you have a reason to keep manual MQTT entities (e.g.
# you need entities not yet covered by discovery, like the per-temperature
# `timer_prog_temperature[N]` numbers or the log text sink). In that case:
#   - turn OFF the "Enable autodiscovery" toggle on the controller, AND
#   - keep `homeassistant: packages: !include_dir_named packages` in
#     configuration.yaml.
#
# Original install instructions (legacy path):
#   1. Confirm `homeassistant: packages: !include_dir_named packages` is set
#      in your main configuration.yaml (see configuration_snippet.yaml).
#   2. Copy this file to <HA_config>/packages/autopool.yaml.
#   3. Copy custom_templates/autopool.jinja to <HA_config>/custom_templates/.
#   4. The MQTT base topic is hard-coded as `autopool` throughout — if your
#      device is configured with a different base (set via the WiFiManager
#      portal, see parameters.mqtt_base_topic), search/replace `autopool/`
#      in this file AND in dashboards/autopool.yaml.
#   5. Restart Home Assistant. Press "Get parameters" and "Get states" once,
#      or wait for the prime automation (it triggers on the first MEAS).
# =============================================================================

# ---------------------------------------------------------------------------
# MQTT entities
# ---------------------------------------------------------------------------
mqtt:

  # ===== Sensors fed by ${base}/MEAS (every 4 s) ===========================
  sensor:

    - name: AutoPool water temperature
      unique_id: autopool_water_temperature
      object_id: autopool_water_temperature
      state_topic: "autopool/MEAS"
      value_template: "{{ value_json.water_temperature }}"
      unit_of_measurement: "°C"
      device_class: temperature
      state_class: measurement
      suggested_display_precision: 1

    - name: AutoPool water temperature raw
      unique_id: autopool_water_temperature_raw
      object_id: autopool_water_temperature_raw
      state_topic: "autopool/MEAS"
      value_template: "{{ value_json.water_temperature_raw }}"
      unit_of_measurement: "°C"
      device_class: temperature
      state_class: measurement
      entity_category: diagnostic

    - name: AutoPool day max water temperature
      unique_id: autopool_day_max_water_temperature
      object_id: autopool_day_max_water_temperature
      state_topic: "autopool/MEAS"
      value_template: "{{ value_json.day_max_water_temperature }}"
      unit_of_measurement: "°C"
      device_class: temperature
      state_class: measurement

    - name: AutoPool system temperature
      unique_id: autopool_system_temperature
      object_id: autopool_system_temperature
      state_topic: "autopool/MEAS"
      value_template: "{{ value_json.system_temperature }}"
      unit_of_measurement: "°C"
      device_class: temperature
      state_class: measurement
      entity_category: diagnostic

    - name: AutoPool system humidity
      unique_id: autopool_system_humidity
      object_id: autopool_system_humidity
      state_topic: "autopool/MEAS"
      value_template: "{{ value_json.system_humidity }}"
      unit_of_measurement: "%"
      device_class: humidity
      state_class: measurement
      entity_category: diagnostic

    - name: AutoPool pump pressure
      unique_id: autopool_pump_pressure
      object_id: autopool_pump_pressure
      state_topic: "autopool/MEAS"
      value_template: "{{ value_json.pump_pressure }}"
      unit_of_measurement: "bar"
      device_class: pressure
      state_class: measurement
      suggested_display_precision: 2

    - name: AutoPool pH
      unique_id: autopool_ph
      object_id: autopool_ph
      state_topic: "autopool/MEAS"
      value_template: "{{ value_json.ph }}"
      state_class: measurement
      icon: mdi:ph
      suggested_display_precision: 2

    - name: AutoPool ORP
      unique_id: autopool_orp
      object_id: autopool_orp
      state_topic: "autopool/MEAS"
      value_template: "{{ value_json.orp | round(0) }}"
      unit_of_measurement: "mV"
      device_class: voltage
      state_class: measurement
      icon: mdi:flash
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

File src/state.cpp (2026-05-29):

#include "autopool.h"

struct StateStructure state = {.filter_mode = FILTER_NOT_SET, .filter_power=FILTER_POWER_NOT_SET};
struct StateStructure state_default;

char state_filter_json_string[STATE_FILTER_CTRL_JSON_MESSAGE_LEN];
char state_ph_json_string[STATE_PH_CTRL_JSON_MESSAGE_LEN];
char state_orp_json_string[STATE_ORP_CTRL_JSON_MESSAGE_LEN];

void filter_state_to_json_string(void)
{
	DynamicJsonBuffer jsonBuffer;
	JsonObject &json = jsonBuffer.createObject();
	json["filter_mode"] = (int)state.filter_mode;
	json["filter_pump"] = (int)state.filter_pump;
	json["filter_control_state"] = (int)state.filter_control_state;
	json["filter_power"] = (int)state.filter_power;
	json["filter_time_pump_on"] = state.filter_time_pump_on;
	json["filter_time_pump_off"] = state.filter_time_pump_off;
	json.printTo(state_filter_json_string, sizeof(state_filter_json_string));
	printA("Filter Json:");
	printlnA(state_filter_json_string);
}

bool filter_state_json_to_state(char *json_str)
{
	DynamicJsonBuffer jsonBuffer;
	JsonObject &json = jsonBuffer.parseObject(json_str);
	if (json.success())
	{
		state.filter_mode = (filter_mode_t)(int)json["filter_mode"];
		state.filter_pump = (pump_state_t)(int)json["filter_pump"];
		state.filter_control_state = (filter_control_state_t)(int)json["filter_control_state"];
		state.filter_power = (filter_power_t)(int)json["filter_power"];
		return true;
	}
	else
	{
		return false;
	}
}

void orp_state_to_json_string(void)
{
	DynamicJsonBuffer jsonBuffer;
	JsonObject &json = jsonBuffer.createObject();
	json["orp_mode"] = (int)state.orp_mode;
	json["orp_pump"] = (int)state.orp_pump;
	json["orp_control_state"] = (int)state.orp_control_state;
	json["orp_time_pump_on"] = state.orp_time_pump_on;
	json["orp_time_pump_off"] = state.orp_time_pump_off;
	json.printTo(state_orp_json_string, sizeof(state_orp_json_string));
	printA("ORP Json:");
	printlnA(state_orp_json_string);
}

bool orp_state_json_to_state(char *json_str)
{
	DynamicJsonBuffer jsonBuffer;
	JsonObject &json = jsonBuffer.parseObject(json_str);
	if (json.success())
	{
		state.orp_mode = (orp_mode_t)(int)json["orp_mode"];
		state.orp_pump = (pump_state_t)(int)json["orp_pump"];
		state.orp_control_state = (orp_control_state_t)(int)json["orp_control_state"];
		return true;
	}
	else
	{
		return false;
	}
}

void ph_state_to_json_string(void)
{
	DynamicJsonBuffer jsonBuffer;
	JsonObject &json = jsonBuffer.createObject();
	json["ph_minus_mode"] = (int)state.ph_minus_mode;
	json["ph_plus_mode"] = (int)state.ph_plus_mode;
	json["ph_minus_pump"] = (int)state.ph_minus_pump;
	json["ph_plus_pump"] = (int)state.ph_plus_pump;
	json["ph_plus_time_pump_on"] = state.ph_plus_time_pump_on;
	json["ph_plus_time_pump_off"] = state.ph_plus_time_pump_off;
	json["ph_minus_time_pump_on"] = state.ph_minus_time_pump_on;
	json["ph_minus_time_pump_off"] = state.ph_minus_time_pump_off;
	json["ph_control_state"] = (int)state.ph_control_state;
	json.printTo(state_ph_json_string, sizeof(state_ph_json_string));
	printA("pH Json:");
	printlnA(state_ph_json_string);
}

bool ph_state_json_to_state(char *json_str)
{
	DynamicJsonBuffer jsonBuffer;
	JsonObject &json = jsonBuffer.parseObject(json_str);
	if (json.success())
	{
		state.ph_minus_mode = (ph_minus_mode_t)(int)json["ph_minus_mode"];
		state.ph_plus_mode = (ph_plus_mode_t)(int)json["ph_plus_mode"];
		state.ph_minus_pump = (pump_state_t)(int)json["ph_minus_pump"];
		state.ph_plus_pump = (pump_state_t)(int)json["ph_plus_pump"];
		state.ph_control_state = (ph_control_state_t)(int)json["ph_control_state"];
		return true;
	}
	else
	{
		return false;
	}
}

bool state_default_write_file(void)
{
	printlnA(F("Saving state to file"));
	DynamicJsonBuffer jsonBuffer;
	JsonObject &json = jsonBuffer.createObject();
	json["ph_minus_mode"] = (int)state.ph_minus_mode;
	json["ph_plus_mode"] = (int)state.ph_plus_mode;
	json["filter_mode"] = (int)state.filter_mode;
	json["orp_mode"] = (int)state.orp_mode;
	json["filter_power"] = (int)state.filter_power;
	json["total_filter_min"] = state.total_filter_min;

	File stateFile = SPIFFS.open(STATE_FILENAME, "w");
	if (!stateFile)
	{
		printlnA(F("failed to open state file for writing"));
		return false;
	}
	json.printTo(stateFile);
	stateFile.close();
	return true;
}

bool state_default_read_file(void)
{
	if (SPIFFS.begin())
	{
		printlnA(F("mounted file system"));
		if (SPIFFS.exists(STATE_FILENAME))
		{
			printlnA(F("reading state file"));
			File configFile = SPIFFS.open(STATE_FILENAME, "r");
			if (configFile)
			{
				printlnA(F("opened state file"));
				size_t size = configFile.size();
				std::unique_ptr<char[]> buf(new char[size]);
				configFile.readBytes(buf.get(), size);
				DynamicJsonBuffer jsonBuffer;
				JsonObject &json = jsonBuffer.parseObject(buf.get());
				if (json.success())
				{
					state_default.filter_mode = (filter_mode_t)(int)json["filter_mode"];
					state_default.orp_mode = (orp_mode_t)(int)json["orp_mode"];
					state_default.ph_minus_mode = (ph_minus_mode_t)(int)json["ph_minus_mode"];
					state_default.ph_plus_mode = (ph_plus_mode_t)(int)json["ph_plus_mode"];
					state_default.filter_power = (filter_power_t)(int)json["filter_power"];
					state_default.total_filter_min = json.containsKey("total_filter_min") ? (uint32_t)json["total_filter_min"] : 0;
					return true;
				}
				else
				{
					printlnA("Json str to parameters fail");
					return false;
				}
			}
		}
	}
	else
	{
		printlnA(F("failed to mount FS"));
		SPIFFS.format();
	}
	return false;
}

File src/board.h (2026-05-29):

#ifndef __BOARD_H__
#define __BOARD_H__

#include <Arduino.h>
#include "config.h"

#define PIN_LED0 2
#define PIN_LED1 12

#define PIN_RELAY_PUMP_PH_P 4
#define PIN_BUZZER 5

#define PIN_DS18B20 13
#define PIN_EXT1 14
#define PIN_EXT2 15

#define PIN_RX2 16
#define PIN_TX2 17

#define PIN_DISPLAY_RX PIN_RX2
#define PIN_DISPLAY_TX PIN_TX2

#define PIN_DHT 18

#define PIN_FLOW 19
#define PIN_SDA 21
#define PIN_SCL 22

#define PIN_RTC_INTERRUPT 23
#define PIN_RELAY_PUMP_CL 25

#define PIN_ADC_INTERRUPT 26

//#define PIN_RELAY_PUMP_FILTER 27
#define PIN_RELAY_PUMP_FILTER PIN_EXT1

#define PIN_RELAY_PUMP_PH_M 32

#ifndef PIN_PUMP_PWR
#define PIN_PUMP_PWR PIN_EXT2
#endif

#define PIN_PRESENCE 33

#define PIN_LEVEL_MIN_CL 34
#define PIN_LEVEL_MIN_PH_M 35
#define PIN_LEVEL_MIN_PH_P 36
#define PIN_LEVEL_MIN_WATER 39

#define ADS_CH_PH 0
#define ADS_CH_CL 1
#define ADS_CH_PRESSURE 2
#define ADS_CH_EXTRA 3

void board_init(void);

void pump_all_off(void);
void pump_ph_minus_on(void);
void pump_ph_minus_off(void);
void pump_ph_plus_on(void);
void pump_ph_plus_off(void);
void pump_ph_cl_on(void);
void pump_ph_cl_off(void);
void pump_filtration_on(void);
void pump_filtration_off(void);

#define PUMP_FILTER_ACTIVE_VALUE true
#define PUMP_FILTER_INACTIVE_VALUE ~PUMP_FILTER_ACTIVE_VALUE

#define PUMP_ACTIVE_VALUE false
#define PUMP_INACTIVE_VALUE ~PUMP_ACTIVE_VALUE

#define PUMP_PWR_FULL_VALUE 1
#define PUMP_PWR_REG_VALUE 0

#define LEVEL_WATER_OK_VALUE true
#define LEVEL_CL_OK_VALUE true
#define LEVEL_PH_MINUS_OK_VALUE true
#define LEVEL_PH_PLUS_OK_VALUE true

inline void led0_off(void) {digitalWrite(PIN_LED0, false);}
inline void led0_on(void) { digitalWrite(PIN_LED0, true); }
inline void led0_toggle(void) { digitalWrite(PIN_LED0, !digitalRead(PIN_LED0)); }
inline void led1_off(void) { digitalWrite(PIN_LED1, false); }
inline void led1_on(void) { digitalWrite(PIN_LED1, true); }
inline void led1_toggle(void) { digitalWrite(PIN_LED1, !digitalRead(PIN_LED1)); }

inline void pump_filtration_on(void) { digitalWrite(PIN_RELAY_PUMP_FILTER, PUMP_FILTER_ACTIVE_VALUE); }
inline void pump_filtration_off(void) { digitalWrite(PIN_RELAY_PUMP_FILTER, 0); }
inline bool pump_filtration_is_on(void) { return digitalRead(PIN_RELAY_PUMP_FILTER) == PUMP_FILTER_ACTIVE_VALUE ? true : false; }

#if HAS_FILTER_PWR_CTRL
inline void pump_filtration_pwr_full(void) { digitalWrite(PIN_PUMP_PWR, PUMP_PWR_FULL_VALUE); }
inline void pump_filtration_pwr_reg(void) { digitalWrite(PIN_PUMP_PWR, PUMP_PWR_REG_VALUE); }
#else 
inline void pump_filtration_pwr_full(void) {}
inline void pump_filtration_pwr_reg(void) {}
#endif

inline void pump_ph_minus_on(void) { digitalWrite(PIN_RELAY_PUMP_PH_M, PUMP_ACTIVE_VALUE); }
inline void pump_ph_minus_off(void) { digitalWrite(PIN_RELAY_PUMP_PH_M, PUMP_INACTIVE_VALUE); }
inline bool pump_ph_minus_is_on(void) { return digitalRead(PIN_RELAY_PUMP_PH_M) == PUMP_ACTIVE_VALUE ? true : false; }

inline void pump_ph_plus_on(void) { digitalWrite(PIN_RELAY_PUMP_PH_P, PUMP_ACTIVE_VALUE); }
inline void pump_ph_plus_off(void) { digitalWrite(PIN_RELAY_PUMP_PH_P, PUMP_INACTIVE_VALUE); }
inline bool pump_ph_plus_is_on(void) { return digitalRead(PIN_RELAY_PUMP_PH_P) == PUMP_ACTIVE_VALUE ? true : false; }

inline void pump_orp_on(void) { digitalWrite(PIN_RELAY_PUMP_CL, PUMP_ACTIVE_VALUE); }
inline void pump_orp_off(void) { digitalWrite(PIN_RELAY_PUMP_CL, PUMP_INACTIVE_VALUE); }
inline bool pump_cl_is_on(void) { return digitalRead(PIN_RELAY_PUMP_CL) == PUMP_ACTIVE_VALUE ? true : false; }

#ifdef DEBUG_PIN1
inline void debug_pin1_off(void) {  digitalWrite(DEBUG_PIN1, false); }
inline void debug_pin1_on(void) { digitalWrite(DEBUG_PIN1, true); }
inline void debug_pin1_toggle(void) { digitalWrite(DEBUG_PIN1, !digitalRead(DEBUG_PIN1)); }
#else
inline void debug_pin1_off(void) {  }
inline void debug_pin1_on(void) {  }
inline void debug_pin1_toggle(void) {  }
#endif

inline void pump_all_off(void)
{
	pump_filtration_off();
	pump_ph_minus_off();
	pump_ph_plus_off();
	pump_orp_off();
}

inline void buzzer_on(void) { digitalWrite(PIN_BUZZER, true); }
inline void buzzer_off(void) { digitalWrite(PIN_BUZZER, false); }

inline bool level_water_is_ok(void) { return digitalRead(PIN_LEVEL_MIN_WATER) == LEVEL_WATER_OK_VALUE ? true : false; }
inline bool level_cl_is_ok(void) { return digitalRead(PIN_LEVEL_MIN_CL) == LEVEL_CL_OK_VALUE ? true : false; }
inline bool level_ph_minus_is_ok(void) { return digitalRead(PIN_LEVEL_MIN_PH_M) == LEVEL_PH_MINUS_OK_VALUE ? true : false; }
inline bool level_ph_plus_is_ok(void) { return digitalRead(PIN_LEVEL_MIN_PH_P) == LEVEL_PH_PLUS_OK_VALUE ? true : false; }

void pump_filtration_off(void);

float dht_get_temperature(void);
float dht_get_humidity(void);
float rtc_get_temperature(void);
uint8_t ds18_count(void);
float ds18_get_temperature(uint8_t index);
float water_get_temperature(void);
float water_get_ph(void);
float water_get_orp(void);
float pump_filtration_get_pressure(bool store_offset);
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

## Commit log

2020-02-03 WIP board definition
2020-02-18 wip 1st board
2020-02-25 Relays control
2020-03-29 First Relays ok
2020-04-17 First 3D
    [autopool_box.FCStd, autopool_box19.FCStd]
2020-04-20 fix screen saver delay
    [ota.cpp]
2020-04-21 Screen saver button
2020-04-21 Adding hardware info
    [autopool.kicad_pcb, autopool.sch]
2020-04-28 removing sleep and reset
    [server.cpp]
2020-05-06 update default flow config
2020-05-18 New IP + Fixed PH and CL levels
    [board.h]
2020-05-26 wip & TFT fix
    [config.h, state.cpp]
2020-06-23 UI: Added pump power button
2020-06-23 Added pump power components
2020-06-23 WIP pump power
    [1130_0.step, 16Bit I2C ADC+PGA - ADS1115.stp, DS3231 Timer Assembly.stp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]
2020-06-25 more filter power preparation
2020-06-28 HMI save ctrl button
2020-07-01 Wip filter temperature mode
2020-07-01 Fixing timer prog
2020-07-02 Added : periodic filter water safe temperature
2020-07-03 Fixing parameter buffer ovf
    [config.h, server.cpp]
2020-07-11 Change power full defaut
2020-07-19 Adding reboot , fixing filter reg
    [board.h, config.h, main.cpp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]
2024-05-05 forced arduino expressif to 2.0.10 for SPIFF
2024-05-06 2.0.13 as latest framework with SPIFF
2024-05-06 reset daily ml from server
    [server.cpp]
2024-05-07 parameters.timer_prog = 0b111111111111000000000000;
2024-09-01 moved filter pump realy to SSR (ext1 pin) changed polarity
2026-05-28 Add Home Assistant MQTT autodiscovery
    Publish retained discovery configs (sensors, binary sensors, selects,
    numbers, buttons) on connect when ha_discovery_enabled is set, with LWT
    availability on {base}/AVAIL and per-field SET/* command handlers so HA
    can drive every mode and setpoint round-trip.
2026-05-28 Replace stub README with comprehensive project documentation
    Covers features, hardware (with pin map and BOM), architecture, build
    and flash workflow, configuration channels, full MQTT topic and SET
    command surface, Home Assistant autodiscovery and manual-package paths,
    web UI, Nextion display, OTA / CLI / Telnet, the ESPHome side track,
    and repo layout.
2026-05-28 Track daily and total filter pump runtime
    Per-minute accumulation in time_update() when filter pump is on. Daily
    counter resets at midnight; total persists across power loss via
    state.json. Surfaced on MQTT MEAS, HA autodiscovery, and the web
    dashboard.
    [main.cpp, state.cpp, state.h]
2026-05-28 Add HA dashboard wired to autodiscovered entities
    Firmware: discovery payloads now carry obj_id so HA assigns clean
    entity_ids of the form <domain>.autopool_<object> (no MAC suffix).
    Adds three previously-missing entities: pressure_warning binary
    sensor (computed against parameters.pressure_warning) plus
    filter_time_pump_on/off diagnostic sensors.
    HA assets: full rewrite of homeassistant/dashboards/autopool.yaml
    using only stock Lovelace cards across 8 sections (Overview, Filter,
    Chemistry, Filter runtime, Tanks & Levels, Trends, Settings,
    Diagnostics & Maintenance). Configuration snippet updated for the
    autodiscovery path; the manual mqtt: package is marked legacy and
    stays available for u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
    [autopool.yaml]
2026-05-28 Support multiple controllers on one MQTT broker
    New optional parameters.device_suffix (lowercase a-z0-9_, max 12) is
    spliced into the MQTT client_id, HA discovery obj_id and device name,
    WiFiManager portal SSID, and OTA mDNS hostname so two units can share
    a broker without colliding. Empty suffix preserves current single-
    device behavior. Setting the suffix auto-rewrites mqtt_base_topic if
    it still has the legacy default, and refreshes HA discovery so old
    entity_ids are cleaned up before the new ones are published.
    [autopool.yaml, ota.cpp, parameters.cpp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]
2026-05-28 Add boot counter reset via MQTT, web, CLI, and HA discovery
    [cli.cpp, server.cpp]
2026-05-29 Add 6-hour axis labels to per-temperature schedule grid
2026-05-29 Persist mode changes from MQTT and web to state.json
    Mode changes via SET/FILTER_MODE, SET/FILTER_POWER, SET/ORP_MODE,
    SET/PH_MINUS_MODE, SET/PH_PLUS_MODE (MQTT) and the equivalent web
    endpoints now call state_default_write_file() so the chosen mode
    survives a reboot. Save is intentionally in the user-facing handlers
    rather than inside *_enter_mode() to avoid persisting automated
    forced-OFF states (e.g. daily dosing limit reached).
    [server.cpp]
2026-05-29 Add current-state highlights and per-row hour counts to settings timer grids
    - Highlight current hour (amber outline + tint) across fixed and temperature grids
    - Highlight active temperature row (amber left border + tint) when in temp mode,
    matching firmware's day_max_water_temperature index selection logic
    - Show dynamic filtered-hours count (e.g. "6h") per temperature row, updated live
    on checkbox changes and after bulk-fill actions
2026-05-29 Fix intermittent 0°C water temperature on reboot and bump to v2.1
    - board.cpp: disable DS18B20 conversion polling (setCheckForConversion(false))
    and pin resolution to 12-bit so requestTemperatures() uses a fixed 750ms
    delay; ESP32 WiFi interrupts can cause the polling path to return early,
    leaving getTempCByIndex() to read a stale/zero scratchpad
    - measures.cpp: replace the fragile 60-second first-minute window with a
    static first_temp_set flag and a raw_is_valid guard (1–100°C); prevents
    assigning a 0 or 255 (error) raw value as the official water temperature,
    regardless of boot duration
    - measures.cpp: deduplicate MQTT publishes — only send when measures change
    or MQTT_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
    [board.cpp, config.h]
2026-06-06 Round water temp to 1 decimal at read time; expose filter program today
    - Round DS18B20 reading to 1 decimal in ds18_get_temperature() so all consumers (display, MQTT, web) naturally get 1 decimal place
    - Add filter_get_effective_timer_prog() to expose the active 24-bit hourly bitmask (temperature-based or fixed) as filter_prog_today in measures/MQTT discovery
    [board.cpp]
2026-06-13 Throttle MQTT measure publishes to reduce noise-driven traffic
    Add per-sensor delta thresholds so measures.ph/orp/pressure/sys_temp/
    sys_humidity only update when the reading changes meaningfully (avoiding
    memcmp-triggered publishes from ADC jitter). Also add a 2-minute minimum
    publish interval as a belt-and-suspenders backstop; 5-minute heartbeat is
    unchanged.
    Fix MQTT discovery filter time entities to report in hours (daily_filter_h /
    total_filter_h) matching the MEAS JSON fields already used since v2.1.
    [config.h]
2026-10-13 Republish MQTT states on connect and on HA birth message
    PARAM/STATE_*/MEAS are not retained, so HA entities stayed "unknown"
    after an HA restart or a broker reconnect. Publish them all right after
    each MQTT connection and when HA sends "online" on <prefix>/status.
    Retain is avoided because PARAM carries mqtt_pass.
    Also widen the CMD base topic buffer (overflowed with a device suffix)
    and bound the payload copy to MQTT_MAX_PACKET_SIZE.
2026-10-13 Fix bogus values published at boot and HA discovery issues; bump to 2.3
    - Hold MQTT state/measure publishes until setup() has initialized the
    regulators and measures (mqtt_set_ready()); previously the connect in
    mqtt_init() pushed zeroed measures (0°C water temp, 0 counters) and an
    uninitialized filter_power to HA on every reboot
    - Omit water_temperature / day_max_water_temperature from MEAS until the
    first valid DS18B20 reading; sensor templates use default('') so HA
    keeps the last state instead of recording 0
    - Seed day max water temperature from the first valid reading after boot,
    and reset it at midnight from the last valid temperature, not the raw one
    - Enlarge discovery JS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
2026-10-13 Add winter mode with frost protection; bump to 3.0
    Winter mode (toggled from HA, the web UI or MQTT SET/WINTER_MODE, persisted
    in state.json):
    - Replaces the filter program by a short winter window
    (winter_start_hour / winter_duration_h, default 04:00 for 3 h)
    - Frost protection: in AUTO, runs the pump continuously when the outdoor
    temperature pushed by HA (OUTDOOR_TEMP, stale after 30 min) drops to
    frost_threshold, with 1.5 °C hysteresis; falls back to water temperature.
    New filter control state FROST (5). A manual filter OFF wins and only
    raises frost_alert
    - Locks pH-/pH+/ORP to OFF (refused in *_enter_mode for every source) and
    restores the previous modes when winter mode en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
2026-10-14 Add plan for energy-saving frost protection (not implemented yet)
    Winter-mode frost protection currently runs the filter pump
    continuously. Plan: declare frost only when outdoor AND water are cold,
    and run on/off cycles (15 min/h, 30 min/h off-peak 23h-7h), continuous
    only under severe frost. Constants in config.h, no new HA parameters.
